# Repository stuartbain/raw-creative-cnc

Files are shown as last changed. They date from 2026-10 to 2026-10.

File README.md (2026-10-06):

# Components

## Electronics

### Stepper Motors

4 x [Nema 23 Stepper Motor 2.4Nm 4A 57x57x82mm 8mm Shaft 4 Wires](https://www.stepperonline.co.uk/nema-23-stepper-motor-2-4nm-339-87oz-in-4a-57x57x82mm-8mm-shaft-4-wires-23hs32-4004s.html)

 - 8mm shaft diameter
 - 21mm shaft length
 - 15mm D shape cut length
 - 7.5mm D shape diameter

### Stepper Drivers

4 x [DM556T Digital Stepper Driver 1.8-5.6A 20-50VDC for Nema 23, 24, 34 Stepper Motor](https://www.stepperonline.co.uk/digital-stepper-driver-1-8-5-6a-20-50vdc-for-nema-23-24-34-stepper-motor-dm556t.html)

### Power Supplies

Mean Well branded power supplies are recommended for their "good, reliable" power supplies. They have trim pots to adjust the voltages accurately when using a multimeter. Be cautious on AliExpress as there are a number of cheaper Mean Well clones with similar branding and model names which may not have the same quality and reliability as the originals.

#### 48V

1 x [LRS-600-48 MEANWELL 600W 48VDC 12.5A 115/230VAC Enclosed Switching Power Supply](https://www.stepperonline.co.uk/lrs-600-48-meanwell-600w-48vdc-12-5a-115-230vac-enclosed-switching-power-supply-lrs-600-48.html)

- Used to power the 4 x 4A stepper motors
 - Adjusted down from 48V to 45V using trim pot and checked with a multimeter. The DM556T stepper drivers support a maximum 50VDC including back EMF generated by the stepper's motion. We provide a 10% overhead to reduce potential damage to the stepper drivers (50V - 10% (5V) = 45V) - Source: [PrintNC Wiki](https://wiki.printnc.info/en/v3/wiring-details#why-adjust-the-48v-power-supply-to-45v)
 - Rule of Thumb for power supply wattage is 2/3 of motor current rating. So 4 x 4A x 45V * 2/3 = 480W - Source: [PrintNC Wiki](https://wiki.printnc.info/en/electronics/steppers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)

#### 24V

1 x [MDR-40-24 MEANWELL 40W 24VDC 1.7A 115/230VAC DIN Rail Power Supply](https://www.stepperonline.co.uk/mdr-40-24-meanwell-40w-24vdc-1-7a-115-230vac-din-rail-power-supply-mdr-40-24.html)

 - Used to power PiBot 5.88 Ultra controller board and proximity sensors
 - Purchased second hand on eBay

#### 12V

I used a 24V to 12V step down voltage regulator to power the 2 x [12V 80mm Noctua Fans](https://www.noctua.at/en/products/nf-r8-redux-1800-pwm) used for cooling.

1 x [Voltage Regulator DC 8V ~ 40V to 12V 3A 36W Converter](https://www.amazon.co.uk/dp/B0DHQNRVMN)

 - This is overkill for powering 2 x 60mA fans but it is smaller than a separate 12V power supply and runs cool and efficiently.

## Mechanical

### Spindle Mount

1 x [CNC Spindle Motor fixture 65mm](https://s.click.aliexpress.com/e/_c4kX31ed)

- The Raw Creative laser cut Z-Axis Spindle plate has pre-cut holes to suit mounts for various spindle diameters. For my 65mm diameter spindle, this mount matches the holes that are 80mm apart (centre to centre) on the X and 34mm apart (centre to centre) on the Y.



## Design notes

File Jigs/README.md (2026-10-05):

## Jigs

I made my own 3D printed jigs because the RawCNC store was not selling its own jigs or any parts at the time I was building my CNC. I used PETG with 5 wall loops and 30% sparse infill and fill multiline of 2 for rigidity. The jigs are modelled using the exact rail and profile dimensions and use the default compensations from the slicer software. This resulted in a good, wiggle free fit without requiring force.

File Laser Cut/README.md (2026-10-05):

## Laser Cut Parts

Laser cutting services require a separate file for each part. I have taken the original DXF file and split them into into individual files.

### 6mm Parts

* S275 Steel

### 3mm Parts

* CR4 Steel (supplier advised that S275 isn't typically available in thicknesses under 3mm and that CR4 is the standard grade mild steel for that thickness)

## Finishing

I specified "Level 2 - Fully Finished: Parts with consistent surface finish suitable for use as is or for coating/further finishing" because I also wanted the parts powder coated. This removed all dross, fully deburred and edges broken. Conisistent finish on all surfaces.

## Powder Coating

My parts were all powder coated with a dark grey satin finish (Anthracite - RAL 7016).

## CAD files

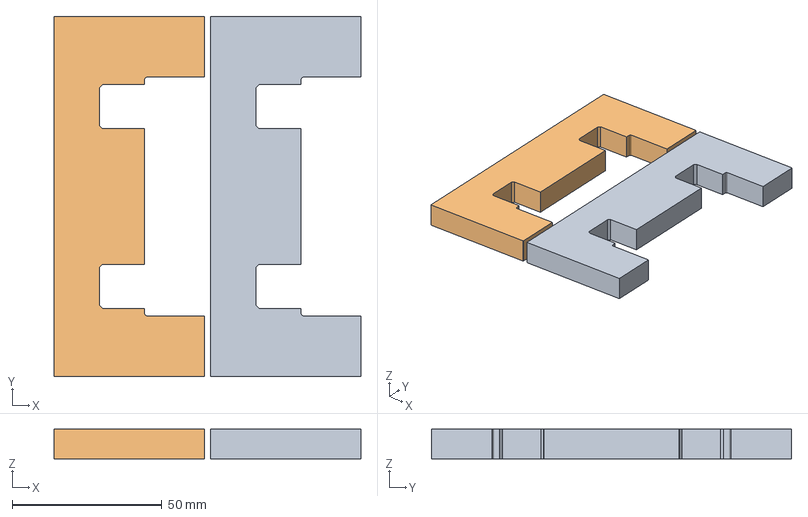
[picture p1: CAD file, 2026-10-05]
Jigs/XY-Rails-jig.3mf
102.5 x 120.3 x 10.00 mm
2080-rails-jig-v1.1 x 2

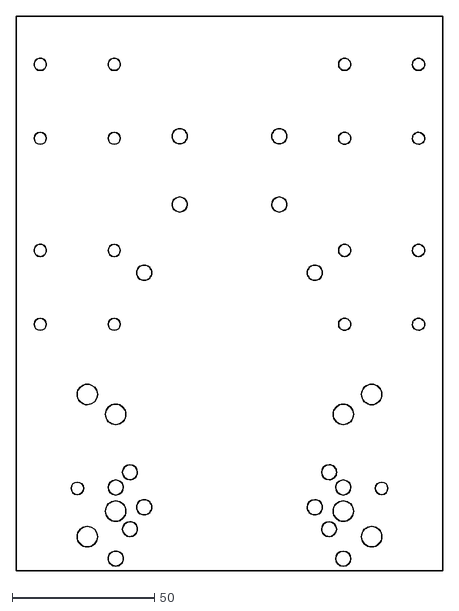
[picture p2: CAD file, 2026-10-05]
Laser Cut/Belt/Z-Spindle-6mm.dxf
150.0 x 195.0

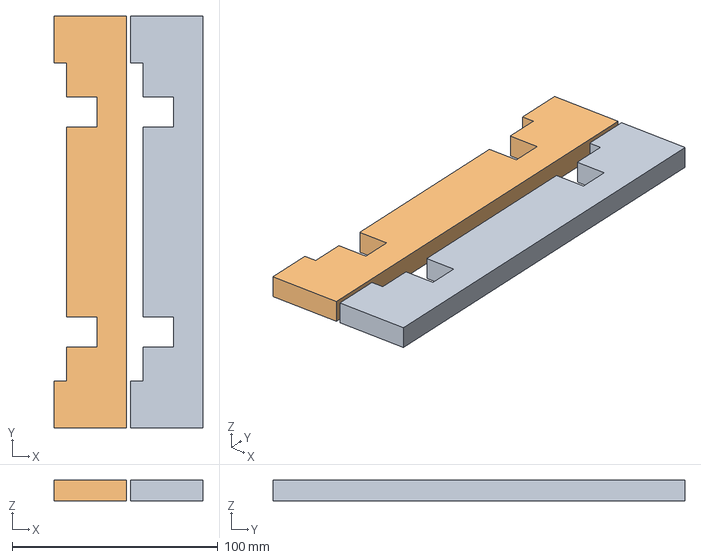
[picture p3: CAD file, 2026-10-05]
Jigs/Z-Rails-Jig.3mf
72.5 x 200.3 x 10.0 mm
Z-Axis-Rails-Jig x 2

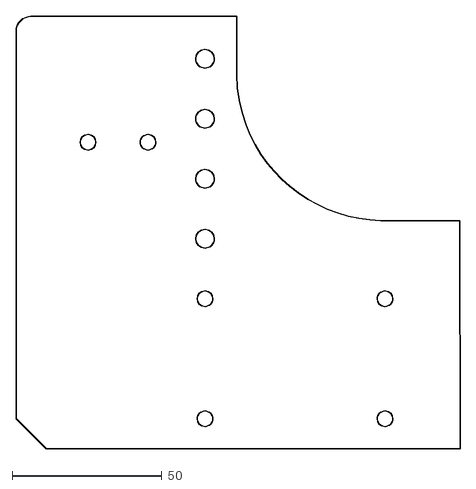
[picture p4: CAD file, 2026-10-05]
Laser Cut/Belt/Corner-6mm-4.dxf
148.0 x 144.2

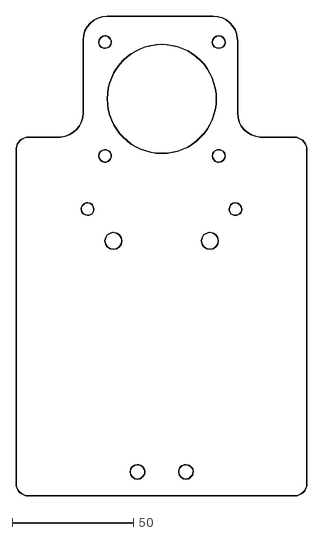
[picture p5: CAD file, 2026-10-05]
Laser Cut/Belt/X-Motor-3mm.dxf
120.0 x 198.1

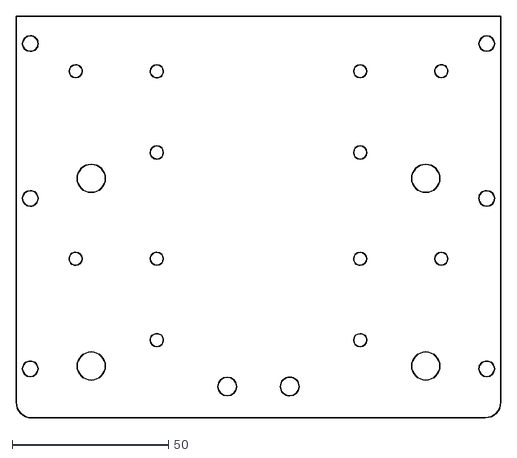
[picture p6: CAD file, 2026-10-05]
Laser Cut/Belt/X-Rails-3mm.dxf
155.0 x 128.5

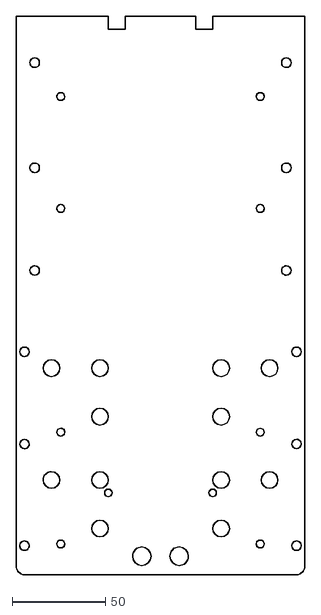
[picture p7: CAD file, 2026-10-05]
Laser Cut/Belt/Z-Rails-6mm.dxf
155.0 x 299.7

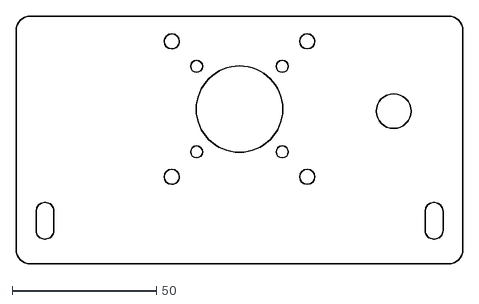
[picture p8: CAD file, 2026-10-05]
Laser Cut/Belt/Z-Top-Motor-6mm.dxf
155.0 x 86.0

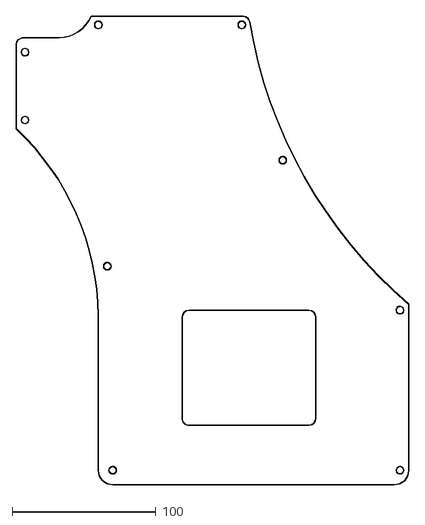
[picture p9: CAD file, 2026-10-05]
Laser Cut/Belt/Y-Side-3mm-2.dxf
272.8 x 325.5

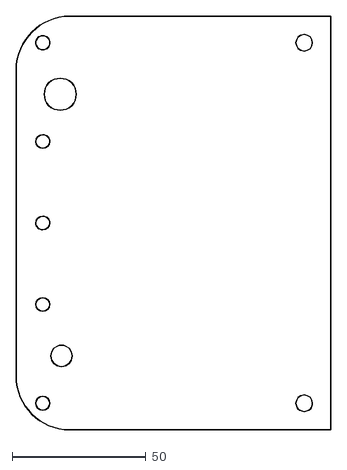
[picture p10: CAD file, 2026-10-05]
Laser Cut/Belt/Z-Bottom-6mm.dxf
117.9 x 155.0

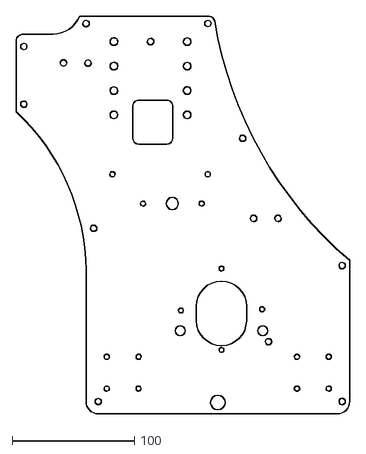
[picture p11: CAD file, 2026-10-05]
Laser Cut/Belt/Y-Side-6mm-2.dxf
272.8 x 325.5

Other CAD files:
Jigs/XY-Rails-jig.dxf
Jigs/Z-Rails-Jig.dxf

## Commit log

2026-10-05 Add Rail Jibs and Belt Laser Cut parts
    [Corner-6mm-4.dxf, X-Motor-3mm.dxf, X-Rails-3mm.dxf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]
2026-10-05 Add Jig and Laser Cut notes
2026-10-06 Add details of Stepper Motors, Drivers and Power Supplies
2026-10-06 Add Spindle Mount details
2026-10-06 Update spindle mount image format and path
